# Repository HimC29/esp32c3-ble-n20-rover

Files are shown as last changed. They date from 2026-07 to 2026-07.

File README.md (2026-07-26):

# esp32c3-ble-n20-rover

An open source tiny ESP32 C3 Super Mini car that is light and fast controlled by a website using BLE.

> This project is still in development and is not stable to use yet.

## Components List

### Core Electronics & Modules
* **1x** ESP32-C3 SuperMini (`U1`)
* **1x** TB6612FNG Motor Driver Module (ROB-14450) (`U2`)
* **1x** MT3608 DC-DC Step-Up Boost Converter Module (`U3`)
* **1x** TP4056 USB-C LiPo Charger Module w/ Protection (`U4`)

### Power & Actuators
* **1x** 3.7V 1000mAh LiPo Battery (`BT1`) (102040)
* **2x** N20 Micro Gear Motors 500RPM 5V-6V (`M1`, `M2`)
* **1x** SPST Toggle / Power Switch (`SW1`)

### Passives & Discrete Components
* **4x** 0.1µF Ceramic Capacitors (`C2`, `C3`, `C4`, `C5`)
* **1x** 100µF Electrolytic Capacitor (`C1`)
* **2x** 100kΩ Resistors (`R1`, `R2`)
* **1x** 0.1Ω Resistor ≥1W (`R3`)
* **1x** Schottky Diode (`D1`) (1N5819)

### Mechanical & Hardware
* **2x** 34mm Wheels (for GA12 N20 shaft)
* **1x** Ball Caster Wheel (3rd support)
* **1x** Chassis / Rover Frame
* Connecting wires, headers, and hardware fasteners

## Wiring
Schematics can be found in [here](schematics/).

## Assembly & Setup
1. Gather all components and wire everything up according to the [schematics](schematics/).
2. Flash the firmware to your ESP32-C3:
   - Open the `firmware/` folder in PlatformIO.
   - Connect your ESP32-C3 via USB.
   - Run `pio run -t upload`.
3. Power on the rover, then open the controller website: **https://himc29.github.io/esp32c3-ble-n20-rover/**
   - **Note:** Web Bluetooth only works in Chromium-based browsers (Chrome, Edge). It is not supported on Safari or iOS at all.
   - If you'd rather self-host the controller instead, the `controller/` folder contains the site — serve it with any static file server. Web Bluetooth requires HTTPS (or `localhost`), so a plain local network address won't work without extra setup.
4. Tap **Connect** and select your device from the browser's Bluetooth picker.
5. Drive using the on-screen controls.

## License
Project is free and open sourced under the MIT License.

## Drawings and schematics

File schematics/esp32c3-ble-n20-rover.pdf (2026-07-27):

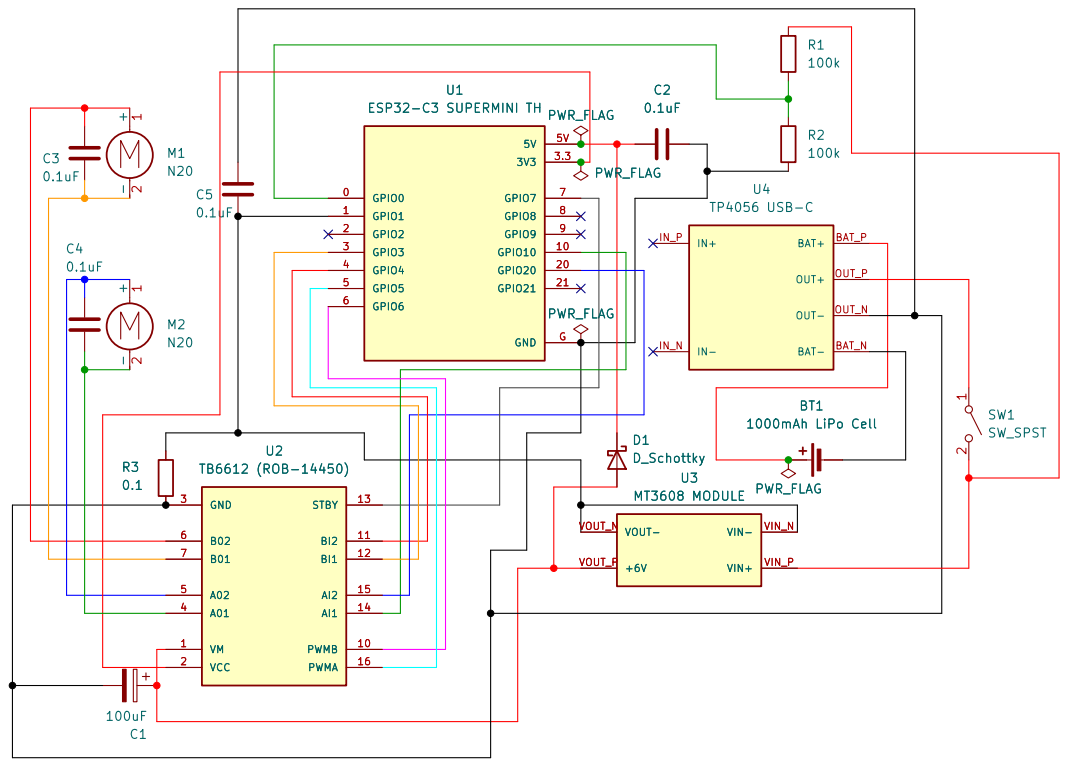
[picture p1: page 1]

Size: A4 | Rev: 0
KiCad E.D.A. 10.0.4 | Id: 1/1

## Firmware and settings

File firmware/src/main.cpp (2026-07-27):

/* esp32c3-ble-n20-rover
 * An open source tiny ESP32 C3 Super Mini car that is light and fast controlled by a website using
   BLE.
 * Open sourced under MIT LICENSE.
 */

#include <Arduino.h>
#include <NimBLEDevice.h>

/* Pin definitions */
/* This pin reads the voltage of the battery through a voltage divider to calculate the percentage
   of the battery.
 */
const uint8_t BAT_VOLT_PIN = 0; 

/* This pin detects spike in current draw from the motor driver using a shunt resistor so that it
 * can shut off the motor before it causes any hardware damage.
 */
const uint8_t CURR_SENSE_PIN = 1;

/* Pins related to motor driver. */
const uint8_t AIN1_PIN = 10;
const uint8_t AIN2_PIN = 20;
const uint8_t BIN1_PIN = 3;
const uint8_t BIN2_PIN = 4;
const uint8_t PWMA_PIN = 5;
const uint8_t PWMB_PIN = 6;
/* STBY pin is a pin on the motor driver. When it is pulled LOW, it turns off all motors 
 * We pull it high so that it turns on.
 */
const uint8_t STBY_PIN = 7;

unsigned long lastPacketMs = 0; /* Store when the last packet was recieved. */
const unsigned long SAFETY_TIMEOUT_MS = 500; /* Stop if no packet recieved within SAFETY_TIMEOUT_MS
                                                ms */

void stopMotors() {
    digitalWrite(AIN1_PIN, LOW);
    digitalWrite(AIN2_PIN, LOW);
    digitalWrite(BIN1_PIN, LOW);
    digitalWrite(BIN2_PIN, LOW);
    analogWrite(PWMA_PIN, 0);
    analogWrite(PWMB_PIN, 0);
}

/* UUID of BLE service. */
const char* SERVICE_UUID = "91fb9ba5-7485-4dc1-9bac-a9889bc524b9";
/* UUID of characteristic. */
const char* CHARACTERISTIC_UUID = "e942f3ad-99c0-48a0-94ad-43792af38a88";

NimBLEServer* pServer = nullptr;
NimBLECharacteristic* pCharacteristic = nullptr;

/* Create a class that inherits from NimBLECharacteristicCallbacks for BLE callbacks. */
class Callbacks : public NimBLECharacteristicCallbacks {
    /* Override the builtin onWrite function from NimBLECharacteristicCallbacks. */
    void onWrite(NimBLECharacteristic* pCharacteristic, NimBLEConnInfo& connInfo) override {
        /* This runs automatically whenever the client writes to this characteristic. */
        std::string value = pCharacteristic->getValue(); /* Get bytes sent by the client. */

        if (value.length() != 4) {
            Serial.println("Invalid packet length");
            return;
        }

        uint8_t leftDir    = value[0];
        uint8_t leftSpeed  = value[1];
        uint8_t rightDir   = value[2];
        uint8_t rightSpeed = value[3];
        
        if (leftSpeed == 0) {
            digitalWrite(AIN1_PIN, LOW);
            digitalWrite(AIN2_PIN, LOW);
        } else if (leftDir == 1) {
            digitalWrite(AIN1_PIN, LOW);
            digitalWrite(AIN2_PIN, HIGH);
        } else {
            digitalWrite(AIN1_PIN, HIGH);
            digitalWrite(AIN2_PIN, LOW);
        }

        if (rightSpeed == 0) {
            digitalWrite(BIN1_PIN, LOW);
            digitalWrite(BIN2_PIN, LOW);
        } else if (rightDir == 1) {
            digitalWrite(BIN1_PIN, LOW);
            digitalWrite(BIN2_PIN, HIGH);
        } else {
            digitalWrite(BIN1_PIN, HIGH);
            digitalWrite(BIN2_PIN, LOW);
        }
        
        analogWrite(PWMA_PIN, leftSpeed);
        analogWrite(PWMB_PIN, rightSpeed);

        lastPacketMs = millis();
    }
};

class ServerCallbacks : public NimBLEServerCallbacks {
    void onConnect(NimBLEServer* pServer, NimBLEConnInfo& connInfo) override {
        Serial.println("Client connected!");
        digitalWrite(STBY_PIN, HIGH);
        stopMotors();
        lastPacketMs = millis();
    }

    void onDisconnect(NimBLEServer* pServer, NimBLEConnInfo& connInfo, int reason) override {
        Serial.printf("Client disconnected, reason: %d\n", reason);
        stopMotors();
        digitalWrite(STBY_PIN, LOW);
        NimBLEDevice::startAdvertising();
    }
};

void setup() {
    Serial.begin(115200);
    Serial.println("Starting");

    pinMode(BAT_VOLT_PIN, INPUT);
    pinMode(CURR_SENSE_PIN, INPUT);
    pinMode(AIN1_PIN, OUTPUT);
    pinMode(AIN2_PIN, OUTPUT);
    pinMode(BIN1_PIN, OUTPUT);
    pinMode(BIN2_PIN, OUTPUT);
    pinMode(PWMA_PIN, OUTPUT);
    pinMode(PWMB_PIN, OUTPUT);
    pinMode(STBY_PIN, OUTPUT);

    /* Set PWM frequency to 20kHz to remove motor whining sounds */
    analogWriteFrequency(PWMA_PIN, 20000);
    analogWriteFrequency(PWMB_PIN, 20000);
    /* Set 8-bit resolution for PWM (0-255) */
    analogWriteResolution(PWMA_PIN, 8);
    analogWriteResolution(PWMB_PIN, 8);

    stopMotors();
    digitalWrite(STBY_PIN, LOW);
    
    /* Initialize BLE with the name esp32c3-ble-n20-rover. */
    NimBLEDevice::init("esp32c3-ble-n20-rover");
    Serial.println("BLE INIT");
    /* Create BLE server */
    pServer = NimBLEDevice::createServer();
    pServer->setCallbacks(new ServerCallbacks());
    Serial.println("SERVER CREATE");
    /* Create service */
    NimBLEService* pService = pServer->createService(SERVICE_UUID);
    Serial.println("SERVICE CREATE");
    
    pCharacteristic = pService->createCharacteristic(
        CHARACTERISTIC_UUID,
        NIMBLE_PROPERTY::WRITE_NR /* WRITE_NR means client can write bytes without response. */
    );
    Serial.println("CHARACTERISTIC CREATE");
    /* Attach callback to pCharacteristic */
    pCharacteristic->setCallbacks(new Callbacks());

    /* Activate the service */
    pService->start();
    Serial.println("SERVICE START");
    /* Advertise the service */
    NimBLEAdvertising* pAdvertising = NimBLEDevice::getAdvertising();
    pAdvertising->addServiceUUID(SERVICE_UUID);
    pAdvertising->enableScanResponse(true);
    NimBLEDevice::startAdvertising();
    Serial.println("ADVERTISE START");
}

void loop() {
    /* If connected but no packets arrive for > SAFETY_TIMEOUT_MS ms, force stop the motors */
    if (pServer->getConnectedCount() > 0 && lastPacketMs > 0) {
        if (millis() - lastPacketMs > SAFETY_TIMEOUT_MS) {
            stopMotors();
        }
    }
    /* Give FreeRTOS time to manage system tasks */
    vTaskDelay(pdMS_TO_TICKS(10));
}

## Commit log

2026-07-25 chore: initial commit with schematics and README
    [esp32c3-ble-n20-rover.kicad_pcb, esp32c3-ble-n20-rover.kicad_sch]
2026-07-25 fix: optimize decoupling capacitors
    [esp32c3-ble-n20-rover.kicad_sch]
2026-07-25 feat: add ESP32-C3 firmware with NimBLE BLE server for motor commands
2026-07-26 chore: ignore KiCad lock files and untrack temporary lck
2026-07-26 docs: change How to create to Assembly & Setup
2026-07-26 feat: add current-sense shunt on boost convertor ground return
    [esp32c3-ble-n20-rover.kicad_sch]
2026-07-26 docs: update components list in readme to match the updated schematics
2026-07-27 feat: update the pins in the firmware code to match the current schematics
2026-07-27 feat: add motor functionality in the firmware code
2026-07-27 docs: update schematic pdf
